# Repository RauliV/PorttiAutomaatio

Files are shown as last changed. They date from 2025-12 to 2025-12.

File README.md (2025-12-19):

# Portin automaatiojärjestelmä

Kattava ratkaisu automaattiseen portinohjaukseen ESP32-mikrokontrollerilla, 12V vinssillä ja täydellä integraatiolla kameravalvontaan.

## 📁 Projektirakenne

```
PorttiAutomaatio/
├── docs/                      # Dokumentaatio
│   ├── mekaniikka.md         # Mekaaninen ja sähköinen dokumentaatio
│   └── readme.md             # Fusion 360 AddIn ohje
├── hardware/                  # Laitteistomäärittelyt
│   ├── mechanical/           # 3D-mallit (STEP, STL)
│   └── electrical/           # Sähkökaaviot
├── firmware/                  # ESP32 firmware
│   ├── src/                  # Lähdekoodit
│   ├── include/              # Header-tiedostot
│   ├── lib/                  # Kirjastot
│   └── platformio.ini        # PlatformIO config
├── fusion360-addon/          # Komponenttien layout-generaattori
│   ├── PorttiKomponentit.py  # Fusion 360 Python API script
│   ├── layout_config.json    # Komponenttimäärittelyt
│   └── manifest.json         # AddIn metadata
└── README.md                 # Tämä tiedosto
```

## 🎯 Ominaisuudet

### Laitteisto
- **Voimansiirto**: 12V DC akku, 80-100A pääsulake, 60A PWM/H-silta
- **Vinssi**: Biltema 15-510 + ketjupyörä + ~2.7m ANSI 40 ketju
- **Ohjaus**: ESP32 (WiFi/MQTT), relekortti, MOSFET-valot
- **Anturit**: Rajakytkimet (IP67), PIR/24GHz liikkeentunnistin
- **Turvallisuus**: Magneettilukko 180kg, RCD-suoja, E-stop
- **Sulanpito**: 230V AC kiskokaapeli, termostaatti-ohjattu

### Ohjelmisto
- **Web-käyttöliittymä**: Selainpohjainen ohjaus
- **MQTT-integraatio**: Home Assistant / ZoneMinder -yhteensopiva
- **HTTP API**: RESTful rajapinta
- **Soft start/stop**: PWM-ramppaus, ylikuormasuojaus
- **Talviprofiili**: Automaattinen sulanpito, jään ravistus

## 🚀 Pika-aloitus

### 1. Laitteiston asennus

Katso yksityiskohtaiset ohjeet: [docs/mekaniikka.md](docs/mekaniikka.md)

**Tl;dr:**
1. Asenna tehokisko: Akku → Pääsulake → PWM/H-silta → Vinssi
2. Kytke ESP32 ja anturit
3. Asenna ketju, kiristin ja rajakytkimet
4. Kytke 230V laturi ja sulanapitovastus

### 2. Firmware

```bash
cd firmware
# Asenna PlatformIO Core (jos ei ole)
pip install platformio

# Konfiguroi WiFi
cp src/config.example.h src/config.h
nano src/config.h  # Aseta WiFi-asetukset

# Buildaa ja flashaa
pio run -t upload
pio device monitor  # Seuraa debug-outputtia
```

### 3. Fusion 360 Layout Generator

**Asennus:**
1. Avaa Fusion 360
2. Scripts and Add-Ins → Add-Ins → vihreä + -painike
3. Valitse `fusion360-addon` -kansio
4. Suorita "PorttiKomponentit"

**Käyttö:**
- Generoi komponenttilayout testauslevylle
- Muokkaa `layout_config.json` muuttaaksesi komponenttien paikkoja
- Käytä layouttia komponenttien sijoitteluun

## 🔌 API-dokumentaatio

### HTTP-rajapinta

```bash
# Avaa portti
curl -X POST http://esp32-ip/open

# Sulje portti
curl -X POST http://esp32-ip/close

# Hae tila
curl http://esp32-ip/status
```

### MQTT

**Komennot** (publish → `gate/cmd`):
```
open    # Avaa portti
close   # Sulje portti
stop    # Pysäytä välittömästi
```

**Tila** (subscribe ← `gate/status`):
```
open     # Täysin auki
closed   # Täysin kiinni
opening  # Aukeamassa
closing  # Sulkeutumassa
stopped  # Pysäytetty
fault    # Vikatila
```

**Anturit**:
- `gate/sensor/motion` - Liikkeentunnistin (true/false)
- `gate/sensor/limit_open` - Auki-rajapääte (true/false)
- `gate/sensor/limit_closed` - Kiinni-rajapääte (true/false)
- `gate/power/voltage` - Akkujännite (V)
- `gate/power/current` - Virta (A)

## 🔐 Turvallisuus

**Pakolliset toiminnot:**
- ✅ E-stop katkaisee virran välittömästi
- ✅ Rajakytkimet estävät yliajon
- ✅ Liikkeentunnistin estää sulkemisen
- ✅ Ylikuormasuoja (>100A → katkaisu)
- ✅ Fail-safe lukitus (auki vain komennolla)
- ✅ Soft start/stop (estää kuormituspiikit)

## 📊 Komponentit

Katso täydellinen lista: [docs/mekaniikka.md](docs/mekaniikka.md#komponenttilista)

**Pääkomponentit:**
- Akku: 12V AGM/Gel 40-70Ah
- PWM/H-silta: 60A jatkuva, 100A peak
- ESP32: WROOM/WROVER dev board
- Ketju: ANSI 40/ISO 08B, 2670mm
- Magneettilukko: 12V DC, ≥180kg

## 🛠️ Kehitys

### Projektin kloonaus ja kehitysympäristö

```bash
git clone https://github.com/[username]/PorttiAutomaatio.git
cd PorttiAutomaatio

# ESP32 firmware
cd firmware
pio run

# Fusion 360 AddIn
# Kopioi fusion360-addon/ Fusion 360 AddIns-kansioon
```

### Testaus

```bash
# ESP32 unit testit
cd firmware
pio test

# Integration testit (vaatii laitteiston)
pio test -e integration
```

## 📝 Lisenssi

MIT License - vapaa käyttöön, muokkaukseen ja jakeluun.

## 👤 Tekijä

**Rauli Virtanen**

- GitHub: [@raulivirtanen](https://github.com/raulivirtanen)
- Projekti: [PorttiAutomaatio](https://github.com/raulivirtanen/PorttiAutomaatio)

## 🤝 Osallistuminen

Pull requestit tervetulleita! Isommille muutoksille avaa ensin issue keskustellaksesi muutoksesta.

## 📚 Lisädokumentaatio

- [Mekaaninen ja sähköinen dokumentaatio](docs/mekaniikka.md)
- [Fusion 360 AddIn käyttöohje](docs/readme.md)
- [API-referenssi](docs/api.md) *(tulossa)*
- [Vianmääritys](docs/mekaniikka.md#vianhaku)

---

**Versio**: 1.0.0  
**Päivitetty**: 2025-12-19

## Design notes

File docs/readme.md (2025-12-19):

# PorttiKomponentit – Layout‑automaation dokumentaatio

## 📑 Sisällysluettelo
- [1. Järjestelmän yleiskuvaus](#1-järjestelmän-yleiskuvaus)
- [2. Add‑inin arkkitehtuuri](#2-add-inin-arkkitehtuuri)
- [3. JSON‑konfiguraation rakenne](#3-json-konfiguraation-rakenne)
- [4. Fusion 360 ‑parametrit](#4-fusion-360--parametrit)
- [5. Layoutin generoinnin työvaiheet](#5-layoutin-generoinnin-työvaiheet)
- [6. Lohkojen sijoittelu ja logiikka](#6-lohkojen-sijoittelu-ja-logiikka)
- [7. Kaapelireitit ja läpiviennit](#7-kaapelireitit-ja-läpiviennit)
- [8. Kiinnitysreiät](#8-kiinnitysreiät)
- [9. Add‑inin käyttö ja asennus](#9-add-inin-käyttö-ja-asennus)
- [10. Laajennettavuus ja jatkokehitys](#10-laajennettavuus-ja-jatkokehitys)

---

## 1. Järjestelmän yleiskuvaus

**PorttiKomponentit** on Fusion 360 ‑add‑in, joka generoi sähkö‑ ja ohjausjärjestelmän layoutin täysin automaattisesti.  
Järjestelmä perustuu **JSON‑konfiguraatioon**, joka määrittelee:

- Testilevyn mitat  
- Lohkojen mitat ja sijainnit  
- Kaapelireitit  
- Läpivientien mitat  
- Kiinnitysreiät  

Add‑in luo **aina täysin uuden layoutin**, eikä päivitä vanhaa.

---

## 2. Add‑inin arkkitehtuuri

### Kansiorakenne

```text
PorttiKomponentit/
 ├── manifest.json
 ├── main.py
 ├── layout_config.json
 └── Resources/
      ├── icon_24.png
      └── icon_32.png
```

### Tiedostojen roolit

| Tiedosto | Kuvaus |
|---|---|
| manifest.json | Add‑inin metatiedot ja pääskriptin nimi |
| main.py | Koko automaation logiikka |
| layout_config.json | Konfiguraatiotiedosto layoutille |
| Resources/ | Toolbar‑painikkeen ikonit |

---

## 3. JSON‑konfiguraation rakenne

JSON sisältää kaiken layoutin määrittelyyn tarvittavan tiedon.

### Rakenne

```json
{
  "plate": { ... },
  "slots": { ... },
  "mount_holes": { ... },
  "blocks": [ ... ],
  "routes": [ ... ]
}
```

### plate – Testilevyn mitat

```json
"plate": {
  "width": 120,
  "height": 60,
  "thickness": 2
}
```

### slots – Läpivientien mitat

```json
"slots": {
  "width": 6,
  "height": 3
}
```

### mount_holes – Kiinnitysreiät

```json
"mount_holes": {
  "diameter": 5,
  "offset": 8,
  "count": 4,
  "pattern": "corners"
}
```

### blocks – Lohkot

```json
{
  "name": "Akku",
  "param_name": "akku",
  "width": 40,
  "height": 20,
  "thickness": 3,
  "x_rel": -0.35,
  "y_rel": 0.35
}
```

### routes – Kaapelireitit

```json
["Akku", "Pääsulake"]
```

---

## 4. Fusion 360 ‑parametrit

Add‑in luo automaattisesti seuraavat parametrit:

### Levyn parametrit
- `plate_width`
- `plate_height`
- `plate_thickness`

### Läpivientien parametrit
- `slot_width`
- `slot_height`

### Kiinnitysreiät
- `mount_hole_diameter`
- `mount_hole_offset`

### Lohkoparametrit
Jokaiselle lohkolle:

- `<param_name>_width`
- `<param_name>_height`
- `<param_name>_thickness`

Esimerkki:

```text
esp32_width
esp32_height
esp32_thickness
```

---

## 5. Layoutin generoinnin työvaiheet

Add‑in suorittaa seuraavat vaiheet:

1. Lataa JSON‑konfiguraation  
2. Luo Fusion‑parametrit  
3. Tyhjentää mallin (bodyt ja sketsit)  
4. Luo Testilevyn  
5. Etsii levyn yläpinnan  
6. Luo lohkot JSONin mukaan  
7. Laskee lohkojen keskikohdat  
8. Piirtää kaapelireitit  
9. Luo läpiviennit reittien keskikohtiin  
10. Luo kiinnitysreiät  
11. Nimeää featuret timelineen  
12. Sovittaa näkymän  

---

## 6. Lohkojen sijoittelu ja logiikka

Lohkot sijoitetaan suhteellisilla koordinaateilla:

- `x_rel` = suhteellinen sijainti levyn leveydestä  
- `y_rel` = suhteellinen sijainti levyn korkeudesta  

Keskipiste lasketaan:

```text
x = x_rel * plate_width
y = y_rel * plate_height
```

Lohko extrudoidaan ylöspäin levyn pinnasta.

---

## 7. Kaapelireitit ja läpiviennit

### Kaapelireitit
- Piirretään suorina viivoina lohkojen keskikohtien välille  
- Ovat omassa sketsissään  

### Läpiviennit
- Jokaisen reitin keskikohtaan luodaan suorakulmainen slot  
- Slotin mitat tulevat JSONista  
- Slotit leikataan läpi levyn  

---

## 8. Kiinnitysreiät

Kiinnitysreiät määritellään JSONissa:

- halkaisija  
- offset  
- määrä  
- pattern (tällä hetkellä: corners)

Add‑in luo reiät:

- levyn neljään kulmaan  
- offset‑etäisyydelle reunoista  
- läpivientileikkauksena  

---

## 9. Add‑inin käyttö ja asennus

### Asennus
1. Kopioi kansio Fusionin AddIns‑hakemistoon  
2. Avaa Fusion → Tools → Scripts and Add‑ins  
3. Valitse add‑in → Run  
4. Toolbarissa näkyy painike

### Käyttö
- Paina toolbar‑painiketta  
- Add‑in generoi layoutin alusta  
- Kaikki perustuu JSON‑tiedostoon  

---

## 10. Laajennettavuus ja jatkokehitys

Järjestelmä on suunniteltu laajennettavaksi:

- Useita JSON‑profiileja  
- Komponenttien rotaatio  
- Spline‑muotoiset kaapelireitit  
- 3D‑komponenttien tuonti lohkojen tilalle  
- UI‑parametripaneeli Fusionissa  
- Layoutin päivitystila (ei vain uudelleenluonti)

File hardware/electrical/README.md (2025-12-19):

# Sähkökaaviot

## Tiedostot

Lisää tähän kansioon:
- [ ] Pääkaavio (12V DC tehokisko)
- [ ] Ohjauskaavio (ESP32 + anturit)
- [ ] 230V AC -kaavio (laturi + sulanpito)
- [ ] Liitäntäkaavio (terminal blocks)
- [ ] Kaapelointi (wire routing)

## Formaatit

**Suositellut:**
- PDF (tulostettava)
- KiCad (.kicad_sch) - avoimen lähdekoodin
- Fritzing (.fzz) - havainnollistava

**Vaihtoehdot:**
- Eagle (.sch)
- EasyEDA
- Käsin piirretty + skannaus

## Sisältö

### 1. Tehokaaavio (12V DC)
```
Akku (12V) ---[Pääsulake 80-100A]---[Pääkatkaisin]---+
                                                      |
                                    +----------------+----------------+
                                    |                |                |
                              [PWM/H-silta]    [DC/DC 12->5V]    [Relekortti]
                                    |                |                |
                                [Vinssi]        [ESP32]       [Lukko, Valot]
```

### 2. Ohjauskaavio (ESP32)
- GPIO-pinnit: PIN_PWM_ENABLE, PIN_DIRECTION, jne.
- Anturien kytkennät: pull-up/pull-down resistors
- Optoeristys relekorttiin
- TVS-diodit suojaukseen

### 3. 230V AC -kaavio
- Verkkovirtaliitäntä
- RCD 30mA
- Laturi 230V AC → 12V DC
- Sulanapitovastus + termostaatti/rele

### 4. Kaapelointi
- Kaapelipaksuudet (mm²)
- Värikoodit
- Liitintyypit
- Reititys

## Turvallisuus

**Tarkistettavaa:**
- ✅ Kaikki 230V AC -osat RCD:n takana
- ✅ Maadoitus kaikissa metallikoteloissa
- ✅ Oikeat kaapelipaksuudet (16mm² vinssille)
- ✅ Sulakkeet oikein mitoitettu
- ✅ E-stop katkaisee virran välittömästi
- ✅ TVS-diodit moottorin napojen yli

---

**Huom**: Lisää kaaviot ennen GitHubiin pushaamista!

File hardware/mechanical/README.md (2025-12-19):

# 3D-mallit - Ohjeet

## Fusion 360 -mallin käyttö

**A360-linkki**: https://a360.co/4ql5F3f

### Tiedostojen exporttaus Fusion 360:sta

1. **Avaa design A360:sta**
   - Kopioi linkki: https://a360.co/4ql5F3f
   - Avaa Fusion 360:ssa: File → Open from my computer → Open link

2. **Exporttaa STEP-tiedostot** (suositeltu valmistukseen):
   ```
   File → Export
   - Format: STEP (*.step, *.stp)
   - Refinement: Medium tai High
   - Save to: hardware/mechanical/
   ```

3. **Exporttaa STL-tiedostot** (3D-tulostus):
   ```
   File → Export
   - Format: STL (*.stl)
   - Structure: One file per body
   - Refinement: High
   - Save to: hardware/mechanical/stl/
   ```

4. **Exporttaa PDF-piirustukset**:
   ```
   Luo Drawing → Right-click → Export as PDF
   Save to: hardware/mechanical/drawings/
   ```

## Tarvittavat tiedostot GitHubiin

Exporttaa seuraavat osat erikseen:

### Pääkomponentit
- [ ] Ketjupyörä (hitsattava vinssiin)
- [ ] Kiristin-assembly
- [ ] Laakeripesä + spacers
- [ ] Ketjukotelo
- [ ] Kiinnityslevyt/konsoli
- [ ] ESP32-kotelo (jos suunniteltu)
- [ ] Komponenttilayout-levy (PorttiKomponentit.py:n generoima)

### Piirustukset
- [ ] Assembly-piirustus (yleiskuva)
- [ ] Ketjupyörän piirustus (mitat)
- [ ] Kiristimen piirustus
- [ ] Asennusohjeet kuvina

## Kansiorakenne

```
hardware/mechanical/
├── step/                 # STEP-tiedostot (valmistus)
│   ├── ketjupyora.step
│   ├── kiristin.step
│   ├── laakeripesa.step
│   └── kotelo.step
├── stl/                  # STL-tiedostot (3D-tulostus)
│   ├── kiristin_body.stl
│   ├── kiristin_roller.stl
│   └── kotelo_esp32.stl
├── drawings/             # PDF-piirustukset
│   ├── assembly.pdf
│   ├── ketjupyora.pdf
│   └── installation.pdf
├── images/               # Renderit ja kuvakaappaukset
│   ├── overview.png
│   ├── ketju_detail.png
│   └── assembly_steps.png
└── README.md            # Tämä tiedosto
```

## Mallien päivitys

Jos päivität Fusion 360 -mallia:

1. Tallenna muutokset A360:een
2. Exporttaa päivitetyt tiedostot (STEP/STL)
3. Korvaa vanhat tiedostot `hardware/mechanical/` -kansiossa
4. Päivitä mitat dokumentaatioon (`docs/mekaniikka.md`)
5. Commitoi muutokset:
   ```bash
   git add hardware/mechanical/
   git commit -m "Update: [komponentti] - [muutos]"
   ```

## Valmistusohjeet

### Ketjupyörä
- **Materiaali**: Teräs (S235 tai parempi)
- **Käsittely**: Galvanointi tai maalaus
- **Kiinnitys**: Hitsaus vinssin ulostuloon
- **Toleranssi**: Keskolinjaus ±2mm

### Kiristin
- **Materiaali**: Alumiini tai teräs
- **Jousi**: 50-100N kuormitus
- **Säätövara**: ±50mm
- **Rulla**: Muovipinnoitettu tai laakeroitu

### ESP32-kotelo
- **Materiaali**: ABS tai PETG (3D-tulostus)
- **Tiivistys**: IP54 tai parempi
- **Läpiviennit**: Kaapeleille ja antureille
- **Kiinnitys**: DIN-kisko tai ruuvit

---

**Huom**: Muista lisätä exportoidut tiedostot tähän kansioon ennen GitHubiin pushaamista!

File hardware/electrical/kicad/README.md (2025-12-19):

# KiCad Sähkökaaviot - PorttiAutomaatio

Yksityiskohtaiset sähkökaaviot portin automaatiojärjestelmälle.

## 📁 Rakenne

```
kicad/
├── PorttiAutomaatio.kicad_pro    # Projektitiedosto
├── PorttiAutomaatio.kicad_sch    # Pääarkki (hierarkia)
├── 230v_ac.kicad_sch             # 230V AC järjestelmä
├── 12v_dc.kicad_sch              # 12V DC tehokisko
├── esp32_control.kicad_sch       # ESP32 ohjaus
├── export_schematics.py          # PDF-vienti skripti
├── exports/                      # Viedyt PDF:t
└── README.md                     # Tämä tiedosto
```

## 🚀 Pika-aloitus

### 1. Avaa projekti KiCadissa

```bash
# macOS:
open -a KiCad PorttiAutomaatio.kicad_pro

# tai käynnistä KiCad ja File → Open Project
```

### 2. Navigoi arkkien välillä

- **Pääarkki**: Näyttää hierarkian (3 aliarkkia)
- **230V AC**: Laturi, RCD, sulanapito
- **12V DC**: Akku, PWM, vinssi, DC/DC
- **ESP32**: GPIO-kytkennät, anturit, releet

Klikkaa hierarkia-laatikoita päästäksesi aliarkkeille.

## 📝 Muokkaaminen

### Komponenttien lisääminen

1. Paina `A` (Add Symbol)
2. Etsi komponentti (esim. "ESP32", "Relay", "Fuse")
3. Sijoita kaaviolle
4. Paina `W` (Wire) vetääksesi kytkennät

### GPIO-taulukko (ESP32)

Kopioi tämä `esp32_control.kicad_sch` arkkiin:

| GPIO | Funktio | Suunta | Komponentti |
|---|---|---|---|
| 25 | PWM_ENABLE | OUT | H-silta |
| 26 | PWM_OUTPUT | OUT | H-silta |
| 27 | DIRECTION | OUT | H-silta |
| 32 | LIMIT_OPEN | IN | Rajakytkin |
| 33 | LIMIT_CLOSED | IN | Rajakytkin |
| 34 | MOTION_SENSOR | IN | PIR |
| 35 | E_STOP | IN | Hätäseis |
| 18 | RELAY_LOCK | OUT | Magneettilukko |
| 19 | RELAY_HEATER | OUT | Sulatusrele |
| 23 | MOSFET_LIGHTS | OUT | LED-valot |
| 36 | VOLTAGE_SENSE | ADC | Jännitemittaus |
| 39 | CURRENT_SENSE | ADC | Virran mittaus |
| 4 | TEMP_HEATSINK | ADC | Lämpömittaus |

## 📤 PDF-vienti

### Automaattinen (skripti)

```bash
cd ~/PorttiAutomaatio/hardware/electrical/kicad/
./export_schematics.py
```

**Tulokset**: `exports/` kansiossa
- `PorttiAutomaatio.pdf` (pääarkki)
- `230v_ac.pdf`
- `12v_dc.pdf`
- `esp32_control.pdf`
- `PorttiAutomaatio_complete.pdf` (kaikki yhdistettynä)

### Manuaalinen vienti

1. Avaa arkki KiCadissa
2. **File → Plot**
3. Valitse:
   - Output format: PDF
   - Output directory: `exports/`
   - ✅ Plot border and title block
4. **Plot All Pages**

## 🔧 Komponenttikirjastot

### Sisäänrakennetut (käytettävissä heti)

- `Device`: R, C, L, Fuse, Switch
- `Connector`: Terminal blocks, screw terminals
- `Relay`: Generic relays
- `Motor`: DC motors
- `power`: +12V, GND, +5V

### Lisättävät erikseen

**ESP32 Dev Board:**
```
Symbol Library Manager → Add →
https://github.com/espressif/kicad-libraries
```

**BTS7960 H-silta:**
Luo custom symboli tai käytä generic "Motor Driver"

## 📊 BOM (Bill of Materials) -vienti

```bash
# KiCad CLI:
kicad-cli sch export bom \
  --output exports/BOM.csv \
  PorttiAutomaatio.kicad_sch
```

Tai KiCad:ssa: **Tools → Generate BOM**

## 🔗 Linkit dokumentaatioon

- [schematic.md](../schematic.md) - ASCII-kaaviot ja tekniset tiedot
- [docs/mekaniikka.md](../../../docs/mekaniikka.md) - Asennusohjeet
- [Fusion 360 layout](../layouts/) - 3D komponenttisijoittelu

## 💡 Vinkit

### Nopeat näppäimet

- `A` - Add symbol
- `W` - Wire (johdin)
- `L` - Label (signaalinimi)
- `P` - Power symbol (+12V, GND)
- `M` - Move
- `C` - Copy
- `Del` - Delete
- `E` - Edit properties
- `R` - Rotate

### Parhaita käytäntöjä

1. **Käytä net labeleita**: Nimeä signaalit (esim. "PWM_OUT", "GND")
2. **Hierarkiset kytkennät**: Yhdistä arkit signaaleilla, ei viivoilla
3. **Kommenttitekstit**: Lisää selityksiä (Text tool)
4. **Komponenttiviitteet**: Numeroi johdonmukaisesti (F1, F2, U1, U2...)
5. **Electrical Rules Check**: Tools → ERC (tarkista virheet)

## 🐛 Vianetsintä

### "Symbol not found"
→ Symbol Library Manager: Lisää puuttuvat kirjastot

### "Hierarchical sheet not found"
→ Tarkista että aliarkkit ovat samassa kansiossa

### PDF-vienti ei toimi
→ Asenna KiCad uudelleen tai käytä Manual Plot

### Skripti ei löydä kicad-cli
→ Päivitä polku `export_schematics.py` tiedostossa

## 📞 Tuki

Ongelmia? Kysy:
- [KiCad Forum](https://forum.kicad.info/)
- [KiCad Documentation](https://docs.kicad.org/)

---

**Versio**: 1.0  
**Luotu**: 2025-12-19  
**Tekijä**: PorttiAutomaatio-projekti

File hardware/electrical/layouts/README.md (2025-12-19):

# Komponenttilayout - Exporttausohjeet

## Fusion 360 AddIn -layoutin exporttaus

### 1. Aja AddIn Fusion 360:ssa

1. Avaa Fusion 360
2. Scripts and Add-Ins → Add-Ins → "PorttiKomponentit"
3. Run → Layout generoidaan

### 2. Exporttaa PDF-piirustus

**Vaihtoehto A: Drawing (suositeltu)**
```
1. Create → Drawing
2. Valitse layout-body
3. Luo päänäkymä (Top View)
4. Lisää mittoja tarvittaessa
5. Right-click drawing → Export as PDF
6. Tallenna: component-layout.pdf
```

**Vaihtoehto B: Suora exportti**
```
1. File → Export
2. Type: PDF
3. Tallenna: component-layout.pdf
```

### 3. Exporttaa PNG-kuva

```
1. Aseta näkymä Top View:ksi
2. View Cube → Top
3. Fit to screen (F-näppäin)
4. Piilota gridit: Grid-kuvake pois
5. Capture Image: View → Capture Image
6. Tallenna: component-layout.png (PNG, korkea resoluutio)
```

### 4. Exporttaa johdotuskaavio erikseen

Jos haluat johdotukset selkeämmin:
```
1. Piilota bodies: Browser → Bodies → piilota komponentit
2. Näytä vain sketches: Browser → Sketches → näytä wire routes
3. Capture Image → wiring-diagram.png
```

### 5. Kopioi tiedostot projektin

```bash
# Kopioi exportoidut tiedostot
cp ~/Downloads/component-layout.pdf ~/PorttiAutomaatio/hardware/electrical/layouts/
cp ~/Downloads/component-layout.png ~/PorttiAutomaatio/hardware/electrical/layouts/
cp ~/Downloads/wiring-diagram.png ~/PorttiAutomaatio/hardware/electrical/layouts/

# Tai suoraan Fusion 360:sta:
# Save to: ~/PorttiAutomaatio/hardware/electrical/layouts/
```

---

## Mitä tiedostot sisältävät

**component-layout.pdf/png:**
- 200×120mm komponenttilevy
- 18 komponenttiblokkia mitoilla
- Johdotusreitit komponenttien välillä
- Aukot ja läpiviennit

**wiring-diagram.png:**
- Pelkät johdotusreitit
- Helpompi seurata yhteyksiä
- Voidaan tulostaa erilliseksi kytkentäkaavioksi

---

## Vinkkejä

**Parempi visualisointi:**
- Käytä Visual Style: Shaded with Edges
- Lisää Section Analysis jos haluat nähdä läpileikkauksen
- Animoi assembly jos teit liikkuvia osia

**Mittakaavatulostus:**
1. Drawing → 1:1 scale
2. Tulosta A4:lle
3. Käytä layouttia fyysiseen asennukseen

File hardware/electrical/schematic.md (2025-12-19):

# Sähkökaavio - Portin automaatiojärjestelmä

## Yleiskuva

Järjestelmä koostuu kolmesta pääosasta:
1. **12V DC tehokisko** (akku → vinssi)
2. **Ohjauselektroniikka** (ESP32 + anturit)
3. **230V AC** (laturi + sulanapito)

---

## 1. Tehokisko (12V DC)

```
                    PÄÄSULAKE ANL 100A
                           │
    AKKU 12V               │         PÄÄKATKAISIN 100A
    40-70Ah                │                │
      (+)──────────────────┴────────────────┴─────┬────────────── +12V TEHOKISKO
                                                  │
                                                  ├─────────────────┐
                                                  │                 │
                                            [TVS: SM8S24A]          │
                                                  │                 │
      (-)─────────────────────────────────────────┴─────────────────┴─ GND TEHOKISKO
                                                  │                 │
                                                  │                 │
                    ┌───────────────────────────────┼─────────────────────┐
                    │                               │                     │
                    │                               │                     │
              ┌─────▼─────┐                   ┌─────▼─────┐       ┌──────▼──────┐
              │ PWM/H-SILTA│                   │  DC/DC    │       │ RELEKORTTI  │
              │  60A Cont  │                   │ 12V → 5V  │       │  12V Kelat  │
              │ 100A Peak  │                   │   3A      │       │  4-8 CH     │
              └─────┬─────┘                   └─────┬─────┘       └──────┬──────┘
                    │                               │                     │
                    │                               │              ┌──────┴──────┐
              ┌─────▼─────┐                   ┌─────▼─────┐       │             │
              │   VINSSI  │                   │   ESP32   │   Kanava 1-4:      │
              │ Biltema   │                   │  WROOM/   │   - Magneettilukko │
              │  15-510   │                   │  WROVER   │   - LED-valot      │
              └───────────┘                   └───────────┘   - Sulatusrele    │
                                                              - (vara)          │
                                                              └──────────────────┘

    Kaapelit:
    - Akku → Vinssi: 16mm² (AWG 6), punainen/musta
    - DC/DC: 2.5mm² riittää
    - Relekortti: 1.5mm² riittää
```

### Komponentit ja liitännät

| Komponentti | Tyyppi | Liitäntä | Kaapeli | Huom |
|---|---|---|---|---|
| Akku | 12V 40-70Ah | M8 navat | 16mm² | Maadoitettu miinusnapa |
| Pääsulake | ANL 100A | Sulakepesä | 16mm² | Akun plusnavassa |
| Pääkatkaisin | 100A | Ruuviliittimet | 16mm² | Helposti saavutettava |
| PWM/H-silta | 60A/100A | Terminal blocks | 16mm² tulo, 16mm² lähtö | Jäähdytyslevy |
| DC/DC | 12V→5V 3A | Terminal/screw | 2.5mm² | Eristetty |
| TVS-diodi | SM8S24A | Moottorin navat | - | Ylijännitesuoja |

---

## 2. Ohjauselektroniikka (ESP32)

### GPIO-kytkennät

```
                                ESP32 DEV BOARD
                               ┌─────────────────┐
                               │                 │
    PWM/H-SILTA OHJAUS:        │  GPIO 25 (OUT) ─┼─→ PWM_ENABLE (H-silta)
                               │  GPIO 26 (OUT) ─┼─→ PWM_OUTPUT (PWM signaali)
                               │  GPIO 27 (OUT) ─┼─→ DIRECTION (suunta)
                               │                 │
    RAJAKYTKIMET:              │  GPIO 32 (IN)  ─┼─← LIMIT_OPEN (pull-up)
                               │  GPIO 33 (IN)  ─┼─← LIMIT_CLOSED (pull-up)
                               │                 │
    ANTURIT:                   │  GPIO 34 (IN)  ─┼─← MOTION_SENSOR
                               │  GPIO 35 (IN)  ─┼─← E_STOP (pull-up)
                               │                 │
    RELEET:                    │  GPIO 18 (OUT) ─┼─→ RELAY_LOCK
                               │  GPIO 19 (OUT) ─┼─→ RELAY_HEATER
                               │  GPIO 23 (OUT) ─┼─→ MOSFET_LIGHTS (PWM)
                               │                 │
    ADC (MITTAUKSET):          │  GPIO 36 (ADC) ─┼─← VOLTAGE_SENSE
                               │  GPIO 39 (ADC) ─┼─← CURRENT_SENSE
                               │  GPIO 4  (ADC) ─┼─← TEMP_HEATSINK
                               │                 │
    VIRTA:                     │  5V            ─┼─← DC/DC muunnin
                               │  GND           ─┼─← Ohjausmaa (tähtipiste)
                               └─────────────────┘
```

### Rajakytkin-kytkentä (tyypillinen)

```
    +12V ───┬────┬──────────────┐
            │    │              │
           [R1] [R2]            │
           10k  10k             │
            │    │              │
            │    │              │
        ESP32   ESP32       RAJAKYTKIN
        GP32    GP33        (NC tai NO)
         │       │              │
         └───────┴──────────────┴─── GND

    R1, R2 = 10kΩ pull-up (sisäinen tai ulkoinen)
    Ferriitti helmi signaalijohdossa
    Debounce ohjelmallisesti (50ms)
```

### Liikkeentunnistin (PIR/Tutka)

```
    PIR/TUTKA MODUULI
    ┌─────────────┐
    │ VCC  (5-12V)├──── +12V (tai +5V jos PIR vaatii)
    │ OUT         ├──── ESP32 GPIO 34
    │ GND         ├──── GND
    └─────────────┘
    
    Jos 24GHz tutka:
    - RCWL-0516 tai vastaava
    - 4-28V syöttö
    - 3.3V TTL output → suoraan ESP32:een
```

### MOSFET-kytkentä (LED-valot)

```
                    MOSFET (IRLZ44N tai IRF540)
                         ┌───┐
    ESP32 GP23 ─[R 1kΩ]──┤ G │
                         │   │
    +12V ────────────────┤ D ├──┬──[LED-valonauhaa]──┐
                         │   │  │                    │
                         │ S ├──┴────────────────────┴── GND
                         └───┘
    
    Diodi D-S napojen väliin (valinnainen)
    PWM-taajuus: 1-5 kHz himmennettäville LEDeille
```

### Relekortti (4-8 kanavaa)

```
    OPTOERISTETTY RELEKORTTI
    ┌─────────────────────────┐
    │ VCC (+12V)              │──── +12V
    │ GND                     │──── GND
    │                         │
    │ IN1 (Lukko)             │──── ESP32 GPIO 18
    │ IN2 (Sulatus)           │──── ESP32 GPIO 19
    │ IN3 (vara)              │──── ESP32 GPIO xx
    │ IN4 (vara)              │──── ESP32 GPIO xx
    │                         │
    │ COM1 ────┐              │
    │ NO1      │ Lukko 12V    │──── Magneettilukko (+)
    │          │              │
    │ COM2 ────┐              │
    │ NO2      │ Sulatus 230V │──── Sulanapitovastus (L)
    └─────────────────────────┘
```

### Jännite/Virta-anturit

```
    JÄNNITTEEN MITTAUS (0-20V → 0-3.3V):
    
    +12V ──[R1: 27kΩ]──┬──[R2: 10kΩ]── GND
                       │
                       └─── ESP32 GPIO 36 (ADC)
    
    Jakosuhde: 3.3V / (12V * 10/(27+10)) ≈ 0.91

    VIRRAN MITTAUS (ACS712 tai INA219):
    
    ACS712-30A:
    ┌─────────────┐
    │ VCC (5V)    │──── +5V (DC/DC:stä)
    │ GND         │──── GND
    │ OUT         │──── ESP32 GPIO 39 (ADC)
    │ IP+ IP-     │──── Sarjaan tehokiskoon
    └─────────────┘
    
    Sensitivity: 66mV/A (30A versio)
    Offset: 2.5V (0A)
```

---

## 3. 230V AC -järjestelmä

```
    230V AC VERKKOVIRTA
         L ────┬────────────────────────────────┬─────────────────────────┐
               │                                │                         │
               │                           ┌────▼────┐               ┌────▼────┐
         N ────┼───────────────────────────┤  RCD    ├───────────────┤  RCD    │
               │                           │  30mA   │               │  30mA   │
               │                           └────┬────┘               └────┬────┘
         PE ───┼────────────────────────────────┼─────────────────────────┼─────
               │                                │                         │
               │                           ┌────▼────┐               ┌────▼────┐
               │                           │ LATURI  │               │  RELE   │
               │                           │ 230V AC │               │  230V   │
               │                           │   ↓     │               └────┬────┘
               │                           │ 12V DC  │                    │
               │                           └────┬────┘              ESP32 GPIO 19
               │                                │                    ohjaus
               │                                │                         │
               └───────────────────────────→ AKKU               ┌─────────▼──────────┐
                                              12V               │ SULANAPITOVASTUS   │
                                                                │  230V 20-30W/m    │
                                                                │  Alumiinikiskossa  │
                                                                └────────────────────┘
                                                                        │
                                                                  [Termostaatti]
                                                                   -5...+10°C
                                                                        │
                                                                       PE
```

### 230V Turvallisuus

| Komponentti | Arvo | Tarkoitus |
|---|---|---|
| RCD (laturi) | 30mA | Vikavirtasuoja laturille |
| RCD (sulatus) | 30mA | Vikavirtasuoja vastukselle |
| Maadoitus | PE | Kaikki metallikoterot |
| Sulake | 10A | Sulanapitovastuksen suojaus |
| Termostaatti | -5...+10°C | Aktivoi kun kylmä |

---

## 4. Kaapelointi ja värikoodit

### 12V DC Tehokisko

| Reitti | Kaapeli | Väri | Pituus (arvio) | Liittimet |
|---|---|---|---|---|
| Akku(+) → Sulake | 16mm² | Punainen | 0.3m | M8 kenkä + ANL |
| Sulake → Katkaisin | 16mm² | Punainen | 0.5m | ANL + ruuvi |
| Katkaisin → PWM | 16mm² | Punainen | 1.0m | Ruuvi + terminal |
| PWM → Vinssi (+) | 16mm² | Punainen | 2.0m | Terminal + puristus |
| Akku(-) → GND kisko | 16mm² | Musta | 0.3m | M8 kenkä |
| GND → Vinssi (-) | 16mm² | Musta | 2.0m | Terminal + puristus |
| +12V → DC/DC | 2.5mm² | Punainen | 0.5m | Terminal |
| GND → DC/DC | 2.5mm² | Musta | 0.5m | Terminal |
| +12V → Releet | 2.5mm² | Punainen | 0.5m | Terminal |

### Ohjauskaapelit (ESP32)

| Signaali | Kaapeli | Väri | Pituus | Huom |
|---|---|---|---|---|
| PWM → H-silta | 0.5mm² | Keltainen | 1.0m | Suojattu kaapeli |
| Direction → H-silta | 0.5mm² | Sininen | 1.0m | Suojattu |
| Enable → H-silta | 0.5mm² | Vihreä | 1.0m | Suojattu |
| Rajakytkin Open | 0.5mm² | Valk/Sin | 3.0m | Cat5e/6 |
| Rajakytkin Close | 0.5mm² | Valk/Ora | 3.0m | Cat5e/6 |
| Motion Sensor | 0.5mm² | Valk/Vih | 2.0m | Cat5e/6 |
| E-Stop | 0.5mm² | Punainen | 1.0m | Paksu |

### 230V AC

| Reitti | Kaapeli | Väri | Huom |
|---|---|---|---|
| Verkko → RCD | 3×1.5mm² | L:Rusk, N:Sin, PE:Vih/Kelt | Kiinteä asennus |
| RCD → Laturi | 3×1.5mm² | L:Rusk, N:Sin, PE:Vih/Kelt | - |
| RCD → Rele | 3×1.5mm² | L:Rusk, N:Sin, PE:Vih/Kelt | - |
| Rele → Vastus | 3×1.5mm² | L:Rusk, N:Sin, PE:Vih/Kelt | Ulkoasennus |

---

## 5. Komponenttiluettelo ostoksiin

### Tehosähkö

| # | Komponentti | Speksit | Kpl | Hinta (arvio) | Linkki/Myyjä |
|---|---|---|-----|---|---|
| 1 | Akku | 12V 50Ah AGM | 1 | 150€ | Biltema/Motonet |
| 2 | Pääkatkaisin | 100A 12V | 1 | 20€ | eBay |
| 3 | ANL-sulake | 100A | 2 | 5€ | eBay |
| 4 | Sulakepesä | ANL-koko | 1 | 10€ | eBay |
| 5 | PWM/H-silta | 60A IBT-2 tai BTS7960 | 1 | 15-30€ | AliExpress |
| 6 | TVS-diodi | SM8S24A | 1 | 2€ | Mouser/Digikey |
| 7 | Kaapeli 16mm² | Punainen | 5m | 25€ | Wurth |
| 8 | Kaapeli 16mm² | Musta | 5m | 25€ | Wurth |
| 9 | Puristusliittimet | M8 kaapelikengät | 10 | 15€ | K-Rauta |

### Ohjaus

| # | Komponentti | Speksit | Kpl | Hinta (arvio) | Linkki/Myyjä |
|---|---|---|-----|---|---|
| 10 | ESP32 | WROOM/WROVER Dev Board | 1 | 10€ | AliExpress |
| 11 | DC/DC | 12V→5V 3A eristetty | 1 | 8€ | AliExpress |
| 12 | Relekortti | 4CH 12V optoeristetty | 1 | 8€ | AliExpress |
| 13 | MOSFET | IRLZ44N tai IRF540 | 2 | 3€ | Partco |
| 14 | Rajakytkimet | IP67 mekaaninen rullavarsi | 2 | 20€ | AliExpress |
| 15 | Liikkeentunnistin | RCWL-0516 (24GHz) | 1 | 3€ | AliExpress |
| 16 | Magneettilukko | 12V 180kg | 1 | 25€ | AliExpress |
| 17 | Virta-anturi | ACS712-30A | 1 | 5€ | AliExpress |
| 18 | Cat6 kaapeli | Ulkokäyttö | 20m | 15€ | K-Rauta |

### 230V AC

| # | Komponentti | Speksit | Kpl | Hinta (arvio) | Linkki/Myyjä |
|---|---|---|-----|---|---|
| 19 | Laturi | 230V AC → 12V DC 5A | 1 | 40€ | Biltema |
| 20 | RCD | 30mA 16A | 2 | 60€ | Sähköliike |
| 21 | Sulanapitovastus | 230V 25W/m | 5m | 50€ | Sähköliike |
| 22 | Termostaatti | -5...+10°C | 1 | 25€ | AliExpress |
| 23 | Rele 230V | 16A kelalla 12V | 1 | 8€ | AliExpress |
| 24 | Kaapeli 3×1.5mm² | Ulkokäyttö | 20m | 40€ | K-Rauta |

**Yhteensä arvio**: ~570€ + Vinssi (~100€) + LED-valot (~30€) = **~700€**

---

## 6. Testausjärjestys

### Vaihe 1: Tehokisko (ilman moottoria)

1. Kytke akku, sulake, katkaisin
2. Mittaa jännite kiskossa: 12.0-13.8V
3. Kytke DC/DC, mittaa 5V
4. Testaa relekortti: click-ääni

### Vaihe 2: ESP32 ohjaus

1. Syötä 5V ESP32:lle
2. Flashaa firmware
3. Testaa GPIO:t LED:llä
4. Testaa WiFi/MQTT

### Vaihe 3: Anturit

1. Testaa rajakytkimet: Serial Monitor
2. Testaa liikkeentunnistin: Serial Monitor
3. Testaa jännite/virta-anturit: Serial Monitor

### Vaihe 4: Vinssi (tyhjäkäynti)

1. Kytke vinssi ILMAN KUORMAA
2. Testaa suunta molempiin suuntiin
3. Mittaa virta: <5A tyhjänä
4. Testaa soft start/stop

### Vaihe 5: Vinssi kuormitettuna

1. Lisää kevyt kuorma (10-20kg)
2. Testaa täysi aukiaulo
3. Mittaa virta: 20-40A kuormalla
4. Testaa rajakytkimien pysäytys

### Vaihe 6: Integraatio

1. Testaa MQTT-komennot
2. Testaa liikkeentunnistimen esto
3. Testaa E-stop
4. Testaa ylikuormasuoja

---

## 7. Turvallisuustarkistus

- [ ] E-stop katkaisee virran välittömästi
- [ ] Rajakytkimet estävät yliajon
- [ ] Ylikuormasuoja toimii (>100A)
- [ ] Liikkeentunnistin estää sulkemisen
- [ ] Magneettilukko fail-safe (auki vain komennolla)
- [ ] RCD:t testattu (test-nappi)
- [ ] Kaikki 230V kotelot maadoitettu
- [ ] Kaapelit kiinnitetty, ei kiristystä
- [ ] TVS-diodit asennettu
- [ ] Eristysv astuus >1MΩ (230V osat)

---

**Versio**: 1.0  
**Päivitetty**: 2025-12-19  
**Laatija**: Rauli Virtanen

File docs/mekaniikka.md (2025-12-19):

# Portin automaatiojärjestelmä - Mekaniikka ja sähköistys

## Yleiskuvaus

Automaattinen porttivinssijärjestelmä 12V DC -käyttöisellä vinssillä ja ESP32-pohjaisella ohjauksella. Järjestelmä sisältää verkkovirtalaturin, sulanpitovastuksen ja täyden integraation kameravalvontaan.

## Järjestelmäarkkitehtuuri

### Päätehonsyöttö (12V DC)
- **Akku**: 12V AGM/Gel, 40-70 Ah
- **Pääkatkaisin**: 12V 100A
- **Pääsulake**: ANL/MIDI 80-100A akun plusnavan lähellä
- **Ylläpitolaturi**: 230V AC → 12V DC, pitää akun varattuna

### Moottoriohjaus
- **PWM/H-silta**: 60A jatkuva, >100A hetkellinen
  - PWM-taajuus: 15-20 kHz
  - Ohjaus: ESP32 (ENA/PWM + DIR -signaalit)
- **TVS-diodi**: 24V bidirectional (SM8S24A) moottorin napojen yli
- **LC-suodatin**: 100µH + 470µF 25V PWM-syöttöön

### Vinssi ja mekaaniikka
- **Vinssi**: Biltema 15-510 (tai vastaava 1000-1500kg)
- **Ketjupyörä**: d=50-60mm, 12-15 hammasta, teräs, hitsattu vinssin ulostuloon
- **Ketju**: ANSI 40 / ISO 08B, ruostumaton/galvanoitu, ~2×1335mm
- **Kiristin**: Jousikuormitettu rulla, säätövara ±50mm
- **Laakerit**: 2× 6202-2RS ketjupyörälle
- **Suojaus**: Ketjukotelo, valutusreiät, tiivisteet

### Ohjaus ja anturit
- **ESP32**: WROOM/WROVER dev board
- **DC/DC-muunnin**: 12V→5V, 3A, eristetty
- **Relekortti**: 4-8 kanavaa, 12V kelat
  - Magneettilukko (12V DC, ≥180kg vetovoima)
  - LED-valot (12V, PWM-himmennys)
  - Sulanapitokaapelin ohjaus
- **MOSFET-kanavat**: 30A valoille ja lisäkuormille
- **Rajakytkimet**: 2kpl IP67 mekaaniset rullavarrella (auki/kiinni)
- **Liikkeentunnistin**: IP66 PIR tai 24GHz tutka, estää sulkemisen

### Sulanpito (230V AC)
- **Sulanapitovastus**: 20-30W/m kiskokaapeli
- **Ohjaus**: Termostaatti/NTC + rele
- **Suojaus**: RCD-vikavirtasuoja, maadoitus

## Komponenttilista

### Tehosähkö
| Komponentti | Tyyppi/Arvo | Määrä | Huomiot |
|---|---|---|---|
| Akku | 12V AGM/Gel 40-70Ah | 1 | Syväpurkaussuojalla |
| Pääkatkaisin | 100A 12V | 1 | Helposti saavutettava |
| Pääsulake | ANL/MIDI 80-100A | 1 | + sulakepesä |
| Vinsskaapelit | 16mm² (AWG 6) | 2×5m | Puristuskaapelikengät |
| H-silta/PWM | 60A cont, 100A peak | 1 | 12V DC moottoriohjain |
| TVS-diodi | SM8S24A (24V bidir) | 1 | Ylijännitesuoja |
| LC-suodatin | 100µH + 470µF 25V | 1 | PWM-häiriösuodatus |

### Ohjaus
| Komponentti | Tyyppi/Arvo | Määrä | Huomiot |
|---|---|---|---|
| ESP32 | WROOM/WROVER | 1 | Dev board |
| DC/DC-muunnin | 12V→5V 3A eristetty | 1 | ESP32:n syöttö |
| Relekortti | 4-8 kanavaa 12V | 1 | Optoeristetty |
| MOSFET-moduuli | 30A PWM | 1 | Valojen himmennys |
| Rajakytkimet | IP67 mekaaninen | 2 | Rullavarrella |
| Liikkeentunnistin | PIR/24GHz IP66 | 1 | Turvallisuus |
| Magneettilukko | 12V DC ≥180kg | 1 | + varmistusdiodi |
| LED-valot | 12V 20-60W total | n | Himmennettävät |

### Mekaniikka
| Komponentti | Tyyppi/Arvo | Määrä | Huomiot |
|---|---|---|---|
| Ketju | ANSI 40/ISO 08B | 2670mm | Ruostumaton/galvanoitu |
| Ketjupyörä | d=50-60mm, 12-15T | 1 | Teräs, hitsataan vinssiin |
| Kiristin | Jousikuormitettu | 1 | Säätövara ±50mm |
| Laakerit | 6202-2RS | 2 | + laakeripesät |
| Ketjukotelo | Alumiini/teräs | 1 | Valutusreiät |

### Verkko ja sulanpito
| Komponentti | Tyyppi/Arvo | Määrä | Huomiot |
|---|---|---|---|
| Sulanapitovastus | 230V 20-30W/m | ~5m | Alumiinikiskossa |
| Termostaatti/NTC | -5...+10°C | 1 | Ohjaussignaali ESP32:lle |
| RCD | 30mA | 1 | Vikavirtasuoja |
| Akkulaturi | 230V AC → 12V DC | 1 | Float-lataus |

## Sähköinen rakenne

### Virtareitit

```
230V AC:
Verkko → RCD → Laturi → 12V Akku
     → RCD → Rele → Sulanapitovastus

12V DC:
Akku(+) → Pääsulake → Pääkatkaisin → [Tehokisko]
                                     ├→ PWM/H-silta → Vinssi
                                     ├→ Relekortti → Lukko, Sulatus
                                     └→ DC/DC → ESP32 → Anturit

Ohjaussignaalit:
ESP32 → PWM/H-silta (ENA/PWM, DIR)
ESP32 → Relekortti (4-8 kanavaa)
ESP32 → MOSFET (PWM valoille)
Rajakytkimet → ESP32 (pull-up + debounce)
Liikkeentunnistin → ESP32
```

### Maadoitus ja häiriösuojaus
- **Tähtipiste**: Ohjausmaa yhdessä pisteessä
- **Ferriittihelmet**: Anturisignaaleissa
- **TVS + LC-suodatin**: PWM-häiriöiden minimoimiseksi
- **Optoeristys**: Relekortti ja moottoriohjain

## Mekaaninen rakenne

### Ketjuasennus

1. **Ketjupyörä vinssiin**:
   - Hitsaa ketjupyörä (d=50-60mm) vinssin ulostuloon
   - Varmista keskitys ja linjaus porttikiskon kanssa
   - Laakeroi tarvittaessa erilliselle akselille (vähentää sivuttaiskuormaa)

2. **Ketjureitti**:
   - Pituus: ~2×1335mm (2670mm yhteensä)
   - Kiinnitys porttiin: hitsatut/pultatut kiinnikkeet
   - Ohjainrullat kaarteissa: minimimutkasäde ≥10×ketjun pitch

3. **Kiristin**:
   - Jousikuormitettu rulla ketjun alaosaan
   - Säätövara: ±50mm
   - Oikea kireys: 10-20mm notkahdus keskeltä

4. **Suojaus**:
   - Ketjukotelo: estää takertuminen, suojaa säältä
   - Valutusreiät pohjassa
   - Tiivisteet läpivienneissä

### Toleranssit ja linjaus

- **Ketjupyörän keskolinjaus**: ±2mm
- **Ketjun sivuttaispoikkeama**: max 3mm
- **Kiristimen säätövara**: ±50mm
- **Laakerivälys**: 0.02-0.05mm

## Asennusohjeet (vaiheittain)

### 1. Sähköasennus

**Tehokisko ja suojat:**
```
1. Asenna pääkatkaisin akun läheisyyteen
2. Asenna pääsulake (80-100A) akun plusnavaan
3. Vedä 16mm² kaapelit vinssille (plus ja miinus erikseen)
4. Luo ohjausmaan tähtipiste
```

**PWM/H-silta:**
```
1. Kytke: Akku → Pääsulake → PWM-tulo
2. Kytke: PWM-lähtö → Vinssin moottori
3. Asenna TVS-diodi moottorin napojen yli
4. Asenna LC-suodatin PWM-syöttöön
5. Kytke ohjaussignaalit ESP32:sta (ENA/PWM, DIR)
```

**ESP32 ja apulaitteet:**
```
1. Syötä ESP32 eristetystä DC/DC-muuntimesta (12V→5V)
2. Kytke relekortti ESP32:een (4-8 kanavaa):
   - Kanava 1: Magneettilukko
   - Kanava 2-3: LED-valot (tai MOSFET)
   - Kanava 4: Sulanapitokaapelin ohjaus
3. Kytke H-sillan ohjaussignaalit (ENA/PWM, DIR) ESP32:lle
```

**Anturit:**
```
1. Asenna rajakytkimet portin auki/kiinni -päihin
2. Vedä anturijohdot ESP32:lle (pull-up + häiriösuodatus)
3. Asenna liikkeentunnistin portin edustalle
4. Testaa antureiden toiminta (debug-output ESP32:sta)
```

### 2. Mekaniikka-asennus

**Ketju ja pyörä:**
```
1. Hitsaa ketjupyörä vinssin ulostuloon
   - Varmista keskitys (max ±2mm)
   - Koelinjaa porttikiskon kanssa
2. Asenna ketju porttiin
   - Kiinnitä molempiin päihin
   - Tarkista hammas- ja ketjulinja
3. Asenna kiristin alaosaan
   - Jousikuormitus ~50N
   - Säädä kireys: 10-20mm notkahdus
4. Asenna ohjainrullat tarvittaessa
```

**Laakerointi (jos tarvitaan):**
```
1. Jos ketjupyörä erillisellä akselilla:
   - Käytä 6202-2RS laakereita (2 kpl)
   - Asenna laakeripesät tukevasti
   - Varmista oikea akseliväli
2. Testaa pyöriminen: kevyt, tasainen, ei sivuttaisliikettä
```

**Suojaus:**
```
1. Asenna ketjukotelo
   - Valutusreiät pohjassa
   - Huoltokansi tarkistuksille
2. Tiivistä läpiviennit
3. Maalaa/suojaa ruostumiselta
```

### 3. Sulanapitovastus (230V AC)

```
1. Asenna vastus alumiinikiskoon
2. Kytke ohjaus releelle (ESP32:n kautta)
3. Lisää termostaatti/NTC-anturi (-5...+10°C)
4. Asenna RCD-vikavirtasuoja (30mA)
5. Maadoita kaikki metallirakenteet
```

### 4. Ohjelmisto ja integraatio

**ESP32:**
```
1. Lataa firmware (web-UI + MQTT)
2. Konfiguroi WiFi ja MQTT-broker
3. Aseta rajakytkinlogiikka ja soft start/stop
4. Testaa käsin (debug-näyttö/seriaaliprintti)
```

**ZoneMinder/NVR-integraatio:**
```
1. Konfiguroi webhook/MQTT-triggerit
2. Testaa: kamera havaitsee liikkeen → ESP32 saa signaalin
3. Aseta authorized approach -logiikka
```

**MQTT-julkaisu:**
```
Topics:
- gate/cmd: open|close|stop
- gate/status: open|closed|stopped|fault|moving
- gate/sensor/motion: true|false
- gate/sensor/limit_open: true|false
- gate/sensor/limit_closed: true|false
```

### 5. Testaus

**Kuivaharjoittelu (ilman kuormaa):**
```
1. Soft start/stop PWM:llä
2. Rajakytkimien toiminta
3. Hätäpysäytys
4. Liikkeentunnistimen esto
```

**Kuormitettu testaus:**
```
1. Mittaa virta (pitää olla <60A jatkuvasti)
2. Tarkista jännitehäviö kaapeleissa (<0.5V)
3. Seuraa lämpötiloja (H-silta, kaapelit)
4. Testaa täysi aukiaulo-sulkusykli
```

**Talviprofiili:**
```
1. Aktivoi sulanapitovastus automaattisesti (<+5°C)
2. Testaa jään ravistus (pieni edestakainen liike)
3. Varmista lukituksen toiminta pakkasella
```

## Turvallisuus

### Pakollliset turvaominaisuudet

1. **E-stop**: Hätäpysäytyspainike, katkaisee virran H-sillalta
2. **Rajakytkimet sarjaan**: Estävät yliajon
3. **Fail-safe lukitus**: Lukko kiinni ellei avauskomento aktiivinen
4. **Ylikuormituksen katkaisu**: >100A katkaisu 2s viiveellä
5. **Liikkeentunnistin**: Estää sulkemisen jos liikettä havaitaan
6. **RCD-suoja**: Sulanapitokaapelille (230V AC)
7. **Soft start/stop**: Estää äkilliset kuormituspiikit

### Huolto-ohjeet

**Viikoittain:**
- Tarkista portin toiminta silmämääräisesti
- Kuuntele epänormaalit äänet

**Kuukausittain:**
- Tarkista ketjun kireys ja voitelu
- Puhdista anturit
- Testaa rajakytkimet ja liikkeentunnistin

**Vuosittain:**
- Tarkista kaikki liitokset ja kiristykset
- Mittaa eristysvastuks (>1MΩ)
- Huolla laakerit
- Vaihda kuluneet ketjun osat

## Vianhaku

| Oire | Mahdollinen syy | Korjaus |
|---|---|---|
| Vinssi ei käynnisty | Pääsulake palanut | Vaihda sulake, tutki ylikuorma |
| | Rajakytkin aktiivinen | Tarkista rajakytkimien tila |
| | ESP32 offline | Tarkista WiFi, käynnistä uudelleen |
| Vinssi toimii hitaasti | Akku heikko | Lataa akku, tarkista laturi |
| | Ketju liian kireällä | Löysää kiristintä |
| Ketju hyppää | Liian löysä | Kiristä kiristintä |
| | Kuluneet hampaat | Vaihda ketjupyörä |
| Sulanapito ei toimi | Rele rikki | Vaihda rele |
| | Termostaatti jumissa | Testaa/vaihda termostaatti |
| | RCD lauennut | Tutki maavuoto, nollaa RCD |

## API-dokumentaatio

### HTTP-rajapinta

```
GET  /status          - Portin tila
POST /open            - Avaa portti
POST /close           - Sulje portti
POST /stop            - Pysäytä liike
GET  /sensors         - Kaikkien antureiden tila
POST /light/{0-100}   - Aseta valojen kirkkaus (PWM)
```

### MQTT-viestit

**Komennot (subscribe: gate/cmd):**
```
open   - Avaa portti
close  - Sulje portti
stop   - Pysäytä välittömästi
```

**Tila (publish: gate/status):**
```
open     - Portti täysin auki
closed   - Portti täysin kiinni
opening  - Aukeamassa
closing  - Sulkeutumassa
stopped  - Pysäytetty
fault    - Vikatila
```

**Anturit (publish):**
```
gate/sensor/motion          - true/false
gate/sensor/limit_open      - true/false
gate/sensor/limit_closed    - true/false
gate/power/voltage          - 12.4 (V)
gate/power/current          - 15.2 (A)
gate/temperature/heatsink   - 45.3 (°C)
```

## Liitteet

- `layout_config.json` - Komponenttien sijoittelu ja johdotukset
- `PorttiKomponentit.py` - Fusion 360 add-in layoutin generointiin
- Sähkökaavio (erillinen tiedosto)
- Mekaaniset piirustukset (erillinen tiedosto)

---

**Dokumentin versio**: 1.0  
**Päivitetty**: 2025-12-19  
**Laatija**: Rauli Virtanen

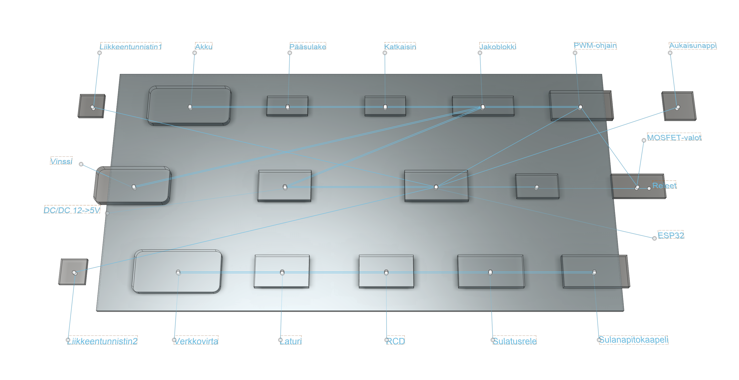
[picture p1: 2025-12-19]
hardware/electrical/layouts/porttikomponentit.png

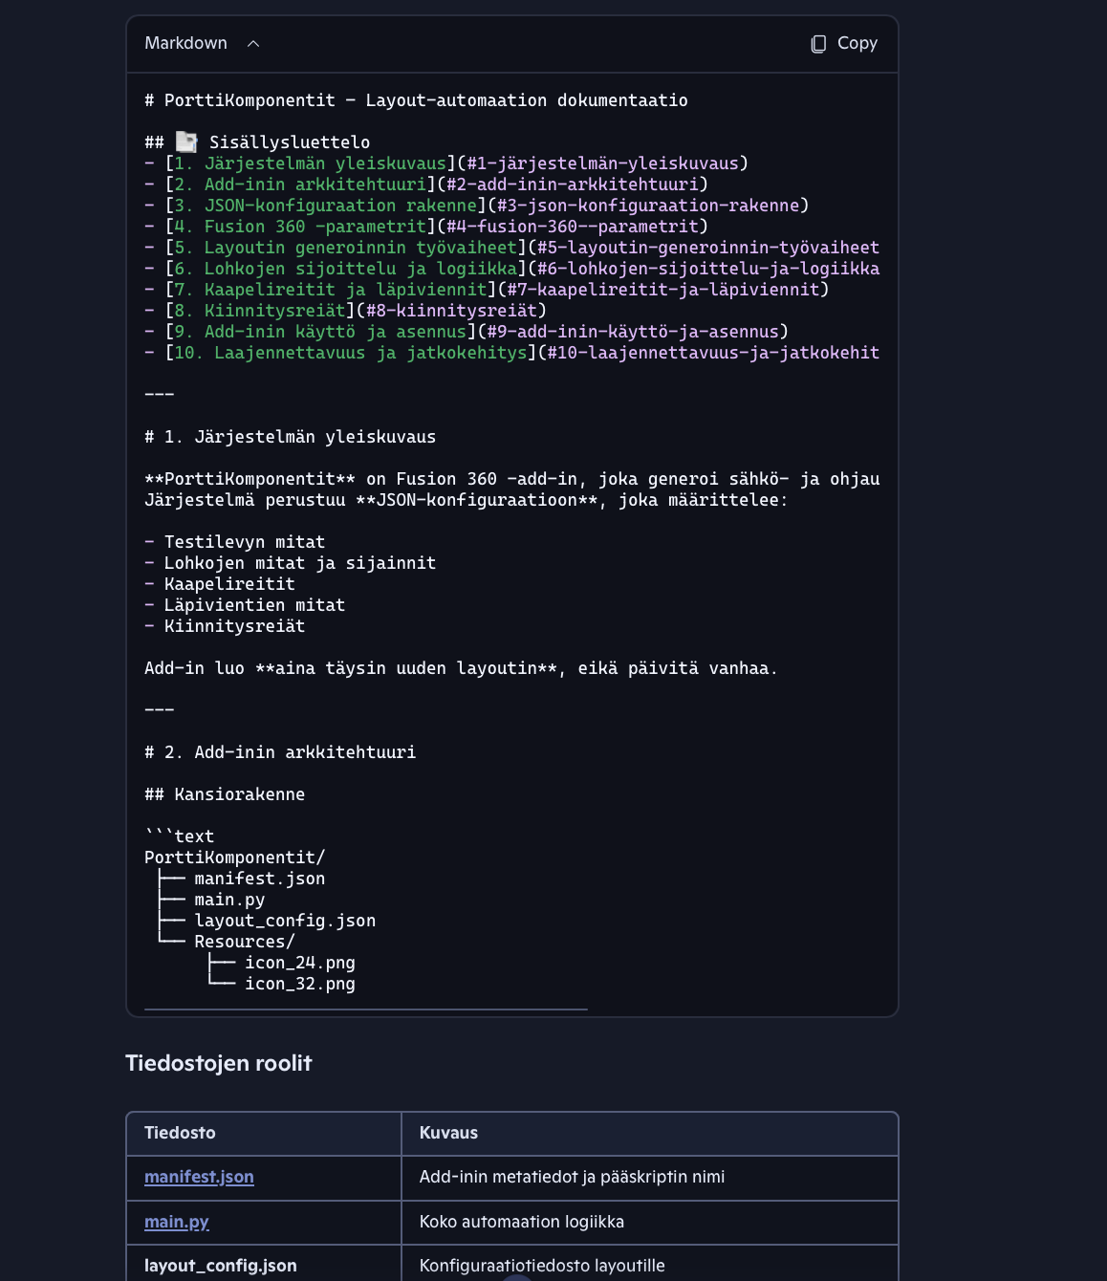
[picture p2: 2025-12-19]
fusion360-addon/image.png

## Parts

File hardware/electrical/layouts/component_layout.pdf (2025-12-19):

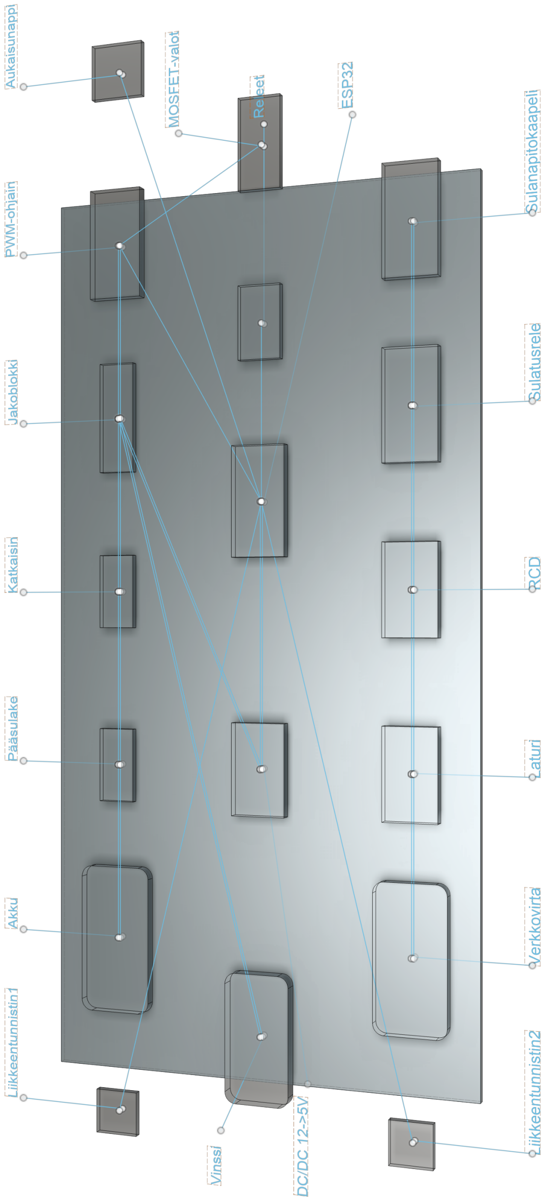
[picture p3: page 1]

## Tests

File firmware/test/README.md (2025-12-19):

# PWM Soft Start/Stop Testi

## 🎯 Tarkoitus
Testaa PWM-ramping logiikka LED:llä ennen oikean moottorin käyttöä.

## 🔌 Kytkentä

```
ESP32 GPIO 26 ──┬──[LED]──[220Ω]──GND
                │
                └── Pitkä jalka (anodi)
```

**Komponentit:**
- 1x LED (mikä tahansa väri)
- 1x 220Ω vastus
- 2x hyppylanka

## 📥 Lataus ESP32:lle

### Vaihtoehto A: PlatformIO
```bash
cd ~/PorttiAutomaatio/firmware
pio run -e pwm_test -t upload -t monitor
```

### Vaihtoehto B: Arduino IDE
1. Avaa `test/pwm_ramp_test.cpp`
2. Valitse **Tools → Board → ESP32 Dev Module**
3. Valitse **Tools → Port → /dev/cu.usbserial-XXX**
4. **Upload** (Ctrl+U)
5. Avaa **Serial Monitor** (115200 baud)

## 👁️ Mitä pitäisi näkyä

### LED:llä:
1. ✅ **Kirkastuu tasaisesti** 2 sekunnissa (ei nykimistä)
2. ✅ **Pysyy täydellä** 2 sekuntia
3. ✅ **Himmenee tasaisesti** 1 sekunnissa
4. ✅ **Paussi** 3 sekuntia
5. ↻ **Toista**

### Serial Monitor:llä:
```
========================================
PWM Soft Start/Stop LED-testi
========================================

✅ PWM konfiguroitu:
   GPIO: 26
   Taajuus: 5000 Hz
   Resoluutio: 8 bit (0-255)

╔════════════════════════════════════════╗
║       UUSI TESTI-SYKLI                ║
╚════════════════════════════════════════╝

🚀 SOFT START:
PWM	Time(ms)	Progress
---	--------	--------
0	0		0.0%
5	40		10.0%
10	80		20.0%
...
255	2000		100.0%
✅ Saavutettu PWM: 255 (2000 ms)

⏸️  Pidetään täydellä kirkkaudella 2s...

🛑 SOFT STOP:
PWM	Time(ms)	Progress
---	--------	--------
255	0		0.0%
250	20		10.0%
...
0	1000		100.0%
✅ Pysäytetty (1000 ms)

💤 Paussi 3s ennen seuraavaa testiä...
```

## ✅ Onnistumiskriteerit

| Testi | Tavoite | Tulos |
|---|---|---|
| **Kirkkaus kasvaa tasaisesti** | Ei nykimistä, sileä fade | ☐ |
| **Aika: 2000ms** | ±100ms | ☐ |
| **Täysi kirkkaus** | LED loistaa täydellä | ☐ |
| **Himmenee tasaisesti** | Sileä fade alas | ☐ |
| **Aika: 1000ms** | ±50ms | ☐ |
| **PWM telemetria** | Arvot 0→255→0 | ☐ |

## 🔧 Parametrien säätö

Muokkaa `pwm_ramp_test.cpp`:ssa:

```cpp
// Hitaampi ramping (sopii raskaammalle portille)
#define START_RAMP_TIME_MS 3000  // 3 sekuntia

// Nopeampi ramping (kevyelle portille)
#define START_RAMP_TIME_MS 1500  // 1.5 sekuntia

// Enemmän askeleita (sileämpi)
#define RAMP_STEPS 100

// Vähemmän askeleita (nykivämpi, mutta toimii)
#define RAMP_STEPS 25
```

## 🚀 Seuraavat vaiheet

Jos LED-testi onnistuu:
1. ✅ **Taso 2**: Pieni moottori (5A)
2. ✅ **Taso 3**: Vinssi penkillä (30A)
3. ✅ **Taso 4**: Oikea portti

## ⚠️ Troubleshooting

**LED ei pala:**
- Tarkista napaisuus (pitkä jalka → GPIO 26)
- Tarkista vastuksen arvo (100Ω-470Ω OK)
- Testaa LED: yhdistä suoraan 3.3V → vastus → GND

**LED vilkkuu, ei fade:**
- PWM-taajuus liian alhainen → nosta 10-20 kHz
- PWM-resoluutio väärä → varmista 8-bit

**Serial ei näytä mitään:**
- Tarkista baud rate (115200)
- Reset ESP32 (EN-nappi)

## 📊 Tulokset

Kun testi valmis, täytä:
- **Päivä**: _______________
- **Ramp time sopiva**: ☐ Kyllä / ☐ Liian hidas / ☐ Liian nopea
- **Smoothness**: ☐ Sileä / ☐ Pieni nykiminen / ☐ Paljon nykimistä
- **Huomiot**: _______________________________________

---

**Valmis seuraavaan vaiheeseen?** → [Taso 2: Pieni moottori](../docs/testing_motor.md)

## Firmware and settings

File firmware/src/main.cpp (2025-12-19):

// Firmware placeholder - ESP32 porttiohjaus
// Tulossa: täysi toteutus järjestelmäkuvauksen mukaisesti

#include <Arduino.h>
#include <WiFi.h>
#include <PubSubClient.h>
#include "config.h"

// Global objects
WiFiClient wifiClient;
PubSubClient mqttClient(wifiClient);

// State variables
enum GateState {
  GATE_CLOSED,
  GATE_OPEN,
  GATE_OPENING,
  GATE_CLOSING,
  GATE_STOPPED,
  GATE_FAULT
};

GateState currentState = GATE_STOPPED;
unsigned long lastStateChange = 0;
bool motionDetected = false;
unsigned long motionDetectedTime = 0;

void setup() {
  Serial.begin(115200);
  Serial.println("\n\n=== Portin ohjausjärjestelmä ===");
  Serial.print("Versio: ");
  Serial.println(DEVICE_VERSION);
  
  // Initialize pins
  pinMode(PIN_PWM_ENABLE, OUTPUT);
  pinMode(PIN_DIRECTION, OUTPUT);
  pinMode(PIN_RELAY_LOCK, OUTPUT);
  pinMode(PIN_RELAY_HEATER, OUTPUT);
  pinMode(PIN_MOSFET_LIGHTS, OUTPUT);
  
  pinMode(PIN_LIMIT_OPEN, INPUT_PULLUP);
  pinMode(PIN_LIMIT_CLOSED, INPUT_PULLUP);
  pinMode(PIN_MOTION_SENSOR, INPUT);
  pinMode(PIN_ESTOP, INPUT_PULLUP);
  
  // Initialize PWM
  ledcSetup(PWM_CHANNEL, PWM_FREQUENCY, PWM_RESOLUTION);
  ledcAttachPin(PIN_PWM_OUTPUT, PWM_CHANNEL);
  ledcWrite(PWM_CHANNEL, 0);
  
  // Ensure motor is stopped
  digitalWrite(PIN_PWM_ENABLE, LOW);
  digitalWrite(PIN_RELAY_LOCK, LOW);
  
  Serial.println("GPIO initialized");
  
  // Connect to WiFi
  WiFi.begin(WIFI_SSID, WIFI_PASSWORD);
  Serial.print("Connecting to WiFi");
  while (WiFi.status() != WL_CONNECTED) {
    delay(500);
    Serial.print(".");
  }
  Serial.println("\nWiFi connected!");
  Serial.print("IP: ");
  Serial.println(WiFi.localIP());
  
  // Setup MQTT
  mqttClient.setServer(MQTT_BROKER, MQTT_PORT);
  mqttClient.setCallback(mqttCallback);
  
  Serial.println("Setup complete - ready!");
}

void mqttCallback(char* topic, byte* payload, unsigned int length) {
  String message;
  for (unsigned int i = 0; i < length; i++) {
    message += (char)payload[i];
  }
  
  Serial.print("MQTT message [");
  Serial.print(topic);
  Serial.print("]: ");
  Serial.println(message);
  
  if (String(topic) == MQTT_TOPIC_CMD) {
    if (message == "open") {
      openGate();
    } else if (message == "close") {
      closeGate();
    } else if (message == "stop") {
      stopGate();
    }
  }
}

void reconnectMQTT() {
  while (!mqttClient.connected()) {
    Serial.print("Connecting to MQTT...");
    if (mqttClient.connect(DEVICE_NAME, MQTT_USER, MQTT_PASSWORD)) {
      Serial.println("connected");
      mqttClient.subscribe(MQTT_TOPIC_CMD);
      publishState();
    } else {
      Serial.print("failed, rc=");
      Serial.print(mqttClient.state());
      Serial.println(" retry in 5s");
      delay(5000);
    }
  }
}

void publishState() {
  const char* stateStr;
  switch (currentState) {
    case GATE_OPEN: stateStr = "open"; break;
    case GATE_CLOSED: stateStr = "closed"; break;
    case GATE_OPENING: stateStr = "opening"; break;
    case GATE_CLOSING: stateStr = "closing"; break;
    case GATE_STOPPED: stateStr = "stopped"; break;
    case GATE_FAULT: stateStr = "fault"; break;
    default: stateStr = "unknown";
  }
  mqttClient.publish(MQTT_TOPIC_STATUS, stateStr, true);
}

void openGate() {
  if (digitalRead(PIN_LIMIT_OPEN) == LOW) {
    Serial.println("Gate already open");
    return;
  }
  
  Serial.println("Opening gate");
  currentState = GATE_OPENING;
  digitalWrite(PIN_DIRECTION, HIGH);
  digitalWrite(PIN_PWM_ENABLE, HIGH);
  ledcWrite(PWM_CHANNEL, MAX_PWM_DUTY);
  publishState();
}

void closeGate() {
  // Check motion sensor
  if (motionDetected && (millis() - motionDetectedTime < MOTION_BLOCK_TIME)) {
    Serial.println("Motion detected - blocking close");
    return;
  }
  
  if (digitalRead(PIN_LIMIT_CLOSED) == LOW) {
    Serial.println("Gate already closed");
    return;
  }
  
  Serial.println("Closing gate");
  currentState = GATE_CLOSING;
  digitalWrite(PIN_DIRECTION, LOW);
  digitalWrite(PIN_PWM_ENABLE, HIGH);
  ledcWrite(PWM_CHANNEL, MAX_PWM_DUTY);
  publishState();
}

void stopGate() {
  Serial.println("Stopping gate");
  digitalWrite(PIN_PWM_ENABLE, LOW);
  ledcWrite(PWM_CHANNEL, 0);
  currentState = GATE_STOPPED;
  publishState();
}

void checkLimitSwitches() {
  static bool lastOpenState = HIGH;
  static bool lastClosedState = HIGH;
  
  bool openState = digitalRead(PIN_LIMIT_OPEN);
  bool closedState = digitalRead(PIN_LIMIT_CLOSED);
  
  // Gate reached open position
  if (openState == LOW && lastOpenState == HIGH && currentState == GATE_OPENING) {
    Serial.println("Gate fully open");
    stopGate();
    currentState = GATE_OPEN;
    publishState();
  }
  
  // Gate reached closed position
  if (closedState == LOW && lastClosedState == HIGH && currentState == GATE_CLOSING) {
    Serial.println("Gate fully closed");
    stopGate();
    currentState = GATE_CLOSED;
    digitalWrite(PIN_RELAY_LOCK, HIGH); // Engage lock
    publishState();
  }
  
  lastOpenState = openState;
  lastClosedState = closedState;
}

void checkMotionSensor() {
  bool motion = digitalRead(PIN_MOTION_SENSOR);
  if (motion && !motionDetected) {
    Serial.println("Motion detected!");
    motionDetected = true;
    motionDetectedTime = millis();
    mqttClient.publish(MQTT_TOPIC_MOTION, "true");
  } else if (!motion && motionDetected) {
    motionDetected = false;
    mqttClient.publish(MQTT_TOPIC_MOTION, "false");
  }
}

void loop() {
  // Maintain MQTT connection
  if (!mqttClient.connected()) {
    reconnectMQTT();
  }
  mqttClient.loop();
  
  // Check sensors
  checkLimitSwitches();
  checkMotionSensor();
  
  // TODO: Implement soft start/stop
  // TODO: Implement overcurrent protection
  // TODO: Implement heating control
  // TODO: Implement web server
  // TODO: Implement voltage/current monitoring
  
  delay(10);
}

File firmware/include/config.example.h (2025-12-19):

#ifndef CONFIG_H
#define CONFIG_H

// WiFi Configuration
#define WIFI_SSID "YourWiFiNetwork"
#define WIFI_PASSWORD "YourWiFiPassword"

// MQTT Configuration
#define MQTT_BROKER "192.168.1.10"
#define MQTT_PORT 1883
#define MQTT_USER "your_mqtt_user"      // Leave empty if no auth
#define MQTT_PASSWORD "your_mqtt_pass"  // Leave empty if no auth

// MQTT Topics
#define MQTT_TOPIC_CMD "gate/cmd"
#define MQTT_TOPIC_STATUS "gate/status"
#define MQTT_TOPIC_MOTION "gate/sensor/motion"
#define MQTT_TOPIC_LIMIT_OPEN "gate/sensor/limit_open"
#define MQTT_TOPIC_LIMIT_CLOSED "gate/sensor/limit_closed"
#define MQTT_TOPIC_VOLTAGE "gate/power/voltage"
#define MQTT_TOPIC_CURRENT "gate/power/current"

// GPIO Pin Configuration
#define PIN_PWM_ENABLE 25        // PWM/H-bridge enable
#define PIN_PWM_OUTPUT 26        // PWM output to motor controller
#define PIN_DIRECTION 27         // Motor direction
#define PIN_LIMIT_OPEN 32        // Limit switch - gate fully open
#define PIN_LIMIT_CLOSED 33      // Limit switch - gate fully closed
#define PIN_MOTION_SENSOR 34     // Motion sensor (PIR/radar)
#define PIN_ESTOP 35             // Emergency stop button
#define PIN_RELAY_LOCK 18        // Magnetic lock relay
#define PIN_RELAY_HEATER 19      // Heating cable relay
#define PIN_MOSFET_LIGHTS 23     // LED lights PWM
#define PIN_VOLTAGE_SENSE 36     // Battery voltage sense (ADC)
#define PIN_CURRENT_SENSE 39     // Current sense (ADC)
#define PIN_TEMP_HEATSINK 4      // Temperature sensor (OneWire/analog)

// Motor Control Settings
#define PWM_FREQUENCY 15000      // 15 kHz PWM frequency
#define PWM_RESOLUTION 8         // 8-bit resolution (0-255)
#define PWM_CHANNEL 0            // PWM channel
#define SOFT_START_DURATION 2000 // Soft start ramp duration (ms)
#define SOFT_STOP_DURATION 1500  // Soft stop ramp duration (ms)
#define MAX_PWM_DUTY 255         // Maximum PWM duty cycle
#define MIN_PWM_DUTY 100         // Minimum PWM to overcome friction

// Safety Settings
#define MAX_CURRENT_AMPS 100.0   // Maximum current before shutdown
#define OVERCURRENT_DELAY 2000   // Time above max current before shutdown (ms)
#define MOTION_BLOCK_TIME 5000   // Block closing for 5s after motion detected
#define DEBOUNCE_TIME 50         // Button debounce time (ms)
#define GATE_TIMEOUT 60000       // Max time for full open/close cycle (ms)

// Heating Settings
#define HEATER_ENABLE_TEMP 5.0   // Enable heating below this temp (°C)
#define HEATER_DISABLE_TEMP 10.0 // Disable heating above this temp (°C)

// Web Server
#define WEB_SERVER_PORT 80

// Device Name
#define DEVICE_NAME "GateController"
#define DEVICE_VERSION "1.0.0"

// Debug Settings
#define DEBUG_SERIAL true
#define DEBUG_VERBOSE false

#endif // CONFIG_H

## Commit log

2025-12-19 Initial commit: PorttiAutomaatio v1.0
    - Complete project structure with docs, firmware, hardware
    - Fusion 360 AddIn for component layout
    - ESP32 firmware skeleton with PlatformIO
    - Electrical schematics and documentation
    - KiCad project templates (3 hierarchical sheets)
    - Mechanical 3D model exports
    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
    [12v_dc.kicad_sch, 230v_ac.kicad_sch, PorttiAutomaatio.kicad_sch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]
2025-12-19 Add 3D model in STEP format (21MB, CAD-compatible)
2025-12-19 Add PWM soft start/stop LED test
    - Test ramping logic with LED before using real motor
    - 50-step smooth fade in/out (2s up, 1s down)
    - Serial telemetry for debugging
    - Test README with connection diagram and checklist
    - Separate PlatformIO test environment
2025-12-19 Add PWM soft start/stop LED test
    - Add Fusion 360 component layout screenshot
    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
